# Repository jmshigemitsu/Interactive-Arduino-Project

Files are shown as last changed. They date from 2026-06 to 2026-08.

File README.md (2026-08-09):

# Interactive Pet Food Dispenser

An Arduino-powered retrofit of a broken pet food dispenser that can be triggered from a live streaming chat. The original dispenser mechanism was modified by replacing one of the motors with a servor, adding a break beam sensor to detect when food is ready to be dispensed, and using a flywheel motor to launch the food.

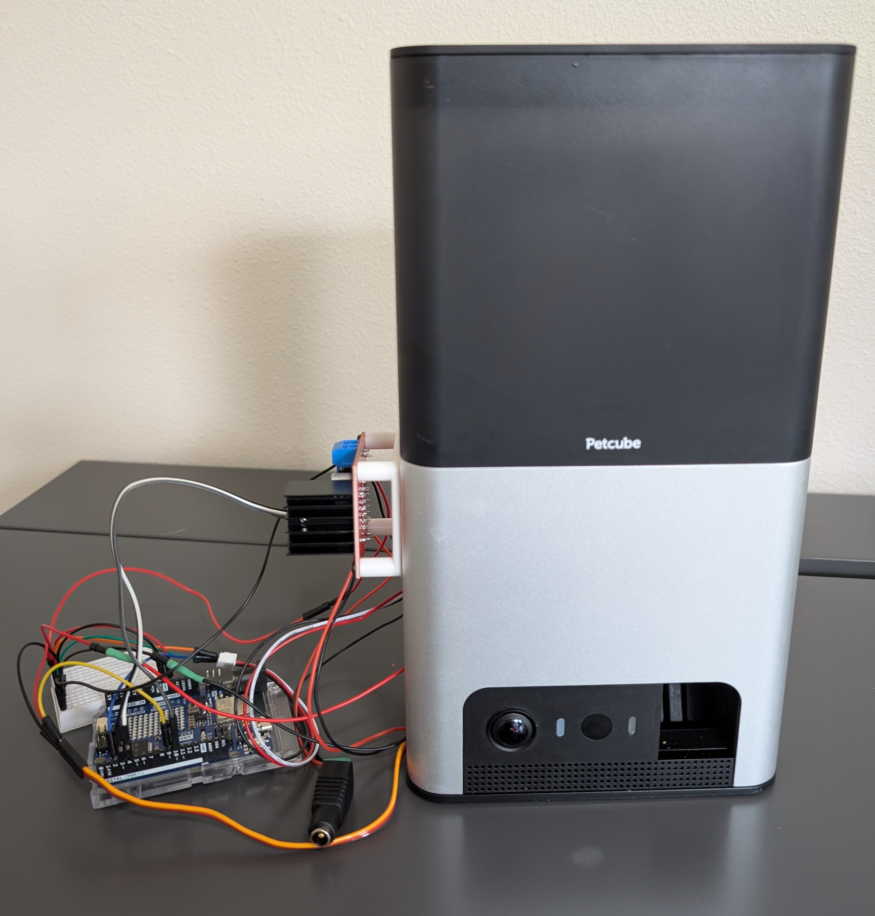
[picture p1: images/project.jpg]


## Project Goal

The goal of this project was to take a broken pet food dispenser and rebuild it into a chat-controlled interactive device for live streams. Viewer commands are handled by a broadcast automation tool, such as Streamer.bot or Mix It Up, which triggers a Python script that sends a serial command to an Arduino. The Arduino loads food using a servo, waits for a break beam sensor to confirm that food is ready, and then runs the flywheel motor to dispense it.

## How It Works

1. A viewer redeems a channel redemption in the live stream chat.
2. A broadcast automation tool recognizes the channel redemption and triggers the python control script.
4. The Python script opens a serial connection to the Arduino and sends the `DISPENSE` command.
5. The Arduino receives the command and starts the dispense sequence.
6. The servo moves back and forth to load food into position.
7. The break beam sensor detects when food interrupts the beam, confirming that food is ready to dispense.
8. Once food is detected, the flywheel motor runs for a set duration to dispense the food.

## Hardware Used

- Arduino Uno
- L298N motor driver board
- DC flywheel motor
- Servo motor
- IR break beam sensor
  - IR transmitter
  - IR receiver
- External power supply
- Breadboard and jumper wires
- Pet food dispenser
- Custom 3D printer parts to integrate new parts with existing parts

## Wiring Diagram

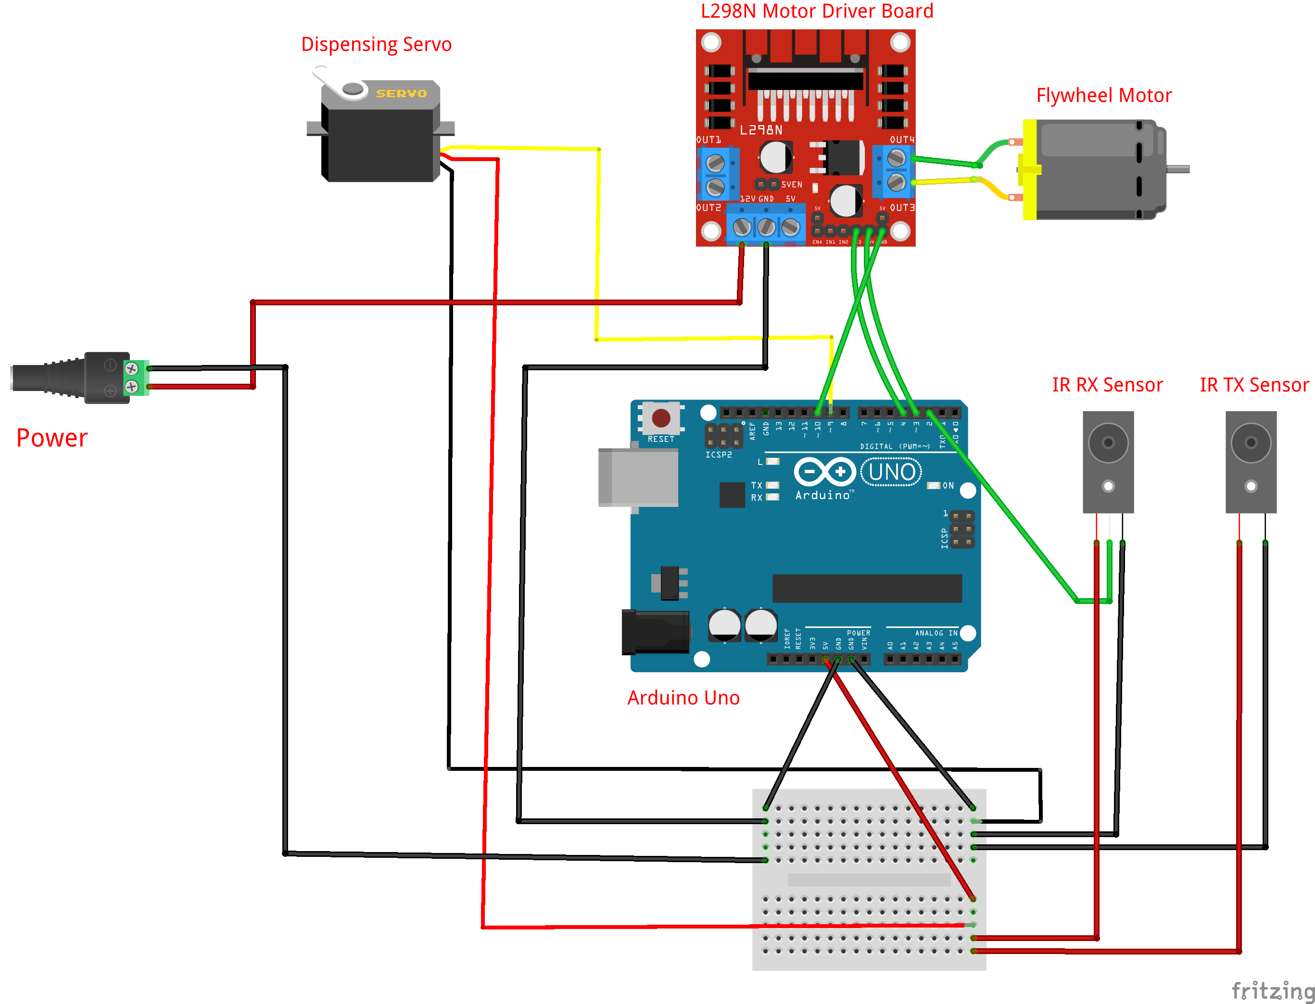
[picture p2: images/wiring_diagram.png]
Wiring Diagram


## Future Improvements

- Replace the breadboard wiring with soldered connections or a protoboard for a more permanent setup.

## Hardware test automation (current phase)

The Python application now talks to the Arduino through `FoodDispenser` in
`dispenser.py`; test code uses this API instead of sending serial bytes itself.
The current protocol is line based:

| Command | Expected response |
| --- | --- |
| `PING` | `PONG` |
| `DISPENSE` | `DISPENSE_OK` |

`main.py` remains the application entry point and sends a dispense request. The
pytest fixture in `tests/conftest.py` loads `SERIAL_PORT` and `BAUD_RATE` from
`.env`, creates a fresh connection for each hardware test, and closes it during
cleanup. The first acceptance check is `tests/test_connection.py`, which calls
`dispenser.ping()`.

1. Upload `firmware/food_dispensor_firmware.ino` to the Arduino.
2. Set the board's serial port and baud rate in `.env` (this local file is not
   committed).
3. Run `./.venv/Scripts/python.exe -m pytest` from PowerShell.

This is a hardware-in-the-loop-style connection test: it validates the real
serial link and firmware response. Simulation, motor/servo/sensor acceptance
criteria, and CI are intentionally deferred until this foundation is proven.

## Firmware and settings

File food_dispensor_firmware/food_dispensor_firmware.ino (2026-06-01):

#include <Servo.h>

// assign pins
int break_beam = 2;
int flywheel_motor_pin_1 = 3;
int flywheel_motor_pin_2 = 4;
int servo_pin = 9;
int speed_pin = 10;
int speed = 150;

// boolean check for sensor
volatile boolean last_sensor_state = false;

// assign flywheel duration
int flywheel_motor_duration = 3000;

// initialize command
String command;

// initialize servo
Servo loading_servo;

void setup() {
  // establish serial communication and pins
  Serial.begin(9600);
  loading_servo.attach(servo_pin);
  pinMode(flywheel_motor_pin_1, OUTPUT);
  pinMode(flywheel_motor_pin_2, OUTPUT);
  pinMode(speed_pin,OUTPUT);
  pinMode(break_beam, INPUT_PULLUP);

  // ensure motor is off at start
  stop_flywheel_motor();
  // Starting servo position
  loading_servo.write(0);
  
  // interrupt
  attachInterrupt(digitalPinToInterrupt(break_beam), sensor_triggered, FALLING);
}


void loop() {
  // wait for serial port to open
  while (!Serial.available()); 
  // read in command from port and trim it
  command = Serial.readString();
  command.trim();
  // if command is DISPENSE then run
  // dispense food method 
  if (command == "DISPENSE"){
    dispense_food();
  } 
}

void sensor_triggered()
{
  last_sensor_state = true;
}

void dispense_food(){
  // rotate servo to load food
  load_food();

  // fire food from hopper
  shoot_food();
  
  // stop flywheel motor
  stop_flywheel_motor();
}

void load_food(){
  // set defaults
  last_sensor_state = false;
  unsigned long previousMillis = millis();

  // if the beam was inturrupted or time out exit while loop
  while (!last_sensor_state && millis() - previousMillis < 10000){
    // move servo clockwise
    loading_servo.write(180);
    delay(700);
    // Move servo counterclockwise
    loading_servo.write(0);
    delay(700);
  }
   // Move servo back to start
   loading_servo.write(0);
   delay(700);
}

void shoot_food(){
  // spin flywheel motor to dispense 
  // food from hopper
  // set motor speed
  analogWrite(speed_pin, speed);
  // spin motor
  digitalWrite(flywheel_motor_pin_1, LOW);
  digitalWrite(flywheel_motor_pin_2, HIGH);
  // run flywheel dispensor motor
  delay(flywheel_motor_duration);
}

void stop_flywheel_motor(){
  // stop flywheel motor
  digitalWrite(flywheel_motor_pin_1, LOW);
  digitalWrite(flywheel_motor_pin_2, LOW);
}

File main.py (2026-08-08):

import os
from dispenser import FoodDispenser
from dotenv import load_dotenv

load_dotenv()

def main():
    # get variables from env file
    port = os.getenv('SERIAL_PORT')
    baud_rate = int(os.getenv('BAUD_RATE'))

    dispenser = FoodDispenser(port,baud_rate)

    try:
        dispenser.connect()
        dispenser.dispense()
    finally:
        dispenser.disconnect()

if __name__ == "__main__":
    main() 

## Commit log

2026-06-01 implement python code for communication to arduino
2026-06-01 switched motor with servo
2026-06-01 fixed loading while logic using interrupt and timeout
    [food_dispensor_firmware.ino]
2026-06-01 adjust servo positions
2026-06-03 add wiring diagram and fritzing
    [food_dispensor_fritzing.fzz]
2026-07-28 updated wiring diagram
    [food_dispensor_fritzing.fzz]
2026-08-08 fixing a lot of the structure to allow for hardware testing
    [food_dispensor_fritzing.fzz]
2026-08-09 Implemented hardware fixture for testing
    [dispenser.py, food_dispensor_firmware.ino]
